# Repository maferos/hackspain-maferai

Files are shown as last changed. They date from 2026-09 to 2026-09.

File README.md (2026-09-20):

# Mafer.ai at HackSpain 2026

Our entry for the Theker track: a robot that prepares fragrance formulas from
a bench of flasks. The operator types a formula into the viewer's chat, or a
brief such as "something fresh and citrusy for summer, light" that a model turns
into one. The robot scans the bench with a fixed camera, drives its wrist camera
over each flask to read the ArUco ring that names the sample, and checks the
formula against what it found: every compound has to be on the bench, in a
flask with enough left for the dose. It then picks each flask in turn while the
panels follow the order step by step, down to the mass on the balance pan. The
lab is a UR10e on a rail, simulated in MuJoCo; the demo also replays the same
scan rendered in Isaac Sim.

Presentation video: https://youtu.be/kdZ4qXKVD1E

Isaac Lab render of a formula end to end: https://youtu.be/przYaTslfyA

Robot lab demo: https://youtu.be/lOhIzaWrY-g

Each part has its own README:

- [`simulation/`](simulation/) — robotic lab-automation simulation with MuJoCo + AutoBio. See [`simulation/README.md`](simulation/README.md).
- [`computer-vision/`](computer-vision/) — computer-vision pipeline: barcode identity, single-camera placement and the vessel detector. See [`computer-vision/README.md`](computer-vision/README.md); the detector choice and its benchmark are in [`computer-vision/docs/BENCHMARK.md`](computer-vision/docs/BENCHMARK.md).
- [`view/`](view/) — robot viewer for the live demo: Isaac Sim renders or live MuJoCo streams, plus task, robot and balance panels. See [`view/README.md`](view/README.md).
- [`dashboard/bridge/`](dashboard/bridge/) — `labbridge`, which publishes the lab state the viewer reads over WebSocket. See [`dashboard/bridge/README.md`](dashboard/bridge/README.md).

## Team

- Eki Gonzalez
- Nacho Gris
- Martí Martinez
- Eloi Torrents

## Requirements

- Python 3.10+ with [`uv`](https://docs.astral.sh/uv/); `simulation/install.sh` creates the venv the viewer backend also uses. The `mujoco` wheel ships the engine and viewer, but AutoBio needs its own MuJoCo 3.3.0 venv and only runs on Linux.
- Node for the viewer frontend (`npm install` in `view/frontend`).
- The MuJoCo Menagerie submodule for the UR10e and gripper meshes: `git submodule update --init third_party/mujoco_menagerie` from `simulation/`.
- A GPU is optional. CPU is enough for the simulation and the panels; detection and rendering are real time only with CUDA or MPS. The Isaac Sim replay videos were rendered on an NVIDIA L4 and are checked in.
- `ANTHROPIC_API_KEY` in `view/backend/.env` for the brief and formula chat; without it the chat falls back to an offline parser.

## Run locally

All from the repo root. The backend runs in `simulation/.venv`, which also
serves the MuJoCo scene.

```sh
# 1. Meshes for the UR10e and the gripper
git submodule update --init simulation/third_party/mujoco_menagerie

# 2. Python venv with the simulation and the viewer backend
(cd simulation && ./install.sh)
uv pip install --python simulation/.venv/bin/python -r view/backend/requirements.txt

# 3. Backend on :8000 (cameras, scan, lab state on :8765). The detector weights
#    are in computer-vision/weights/.
simulation/.venv/bin/python view/backend/server.py

# 4. Frontend on :5173, in another terminal
cd view/frontend && npm install && npm run dev
```

Open http://localhost:5173. Real time shows the live MuJoCo scan; the Replay
switch in the header plays the Isaac Sim recordings for the same bench layout.
Without a backend the panels play the recorded run in `view/frontend/public/scripted-run.json`.
`view/README.md` has the environment variables and the scene selection.

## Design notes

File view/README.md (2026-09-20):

# Robot viewer

Frontend to watch the mini-Hannover MuJoCo scene live: main viewport switchable
between the robot's onboard camera and the fixed scene-overview camera, a
picture-in-picture subwindow showing the other one (click it to swap), and
panels under it that follow the bench scan live, and a chat down the right-hand
side to check a formula against what the scan found.

- `backend/` — FastAPI server. The default rail scene runs the initial bench
  scan from `simulation/scripts/vision_pick.py` with the Robotiq gripper.
  The fixed `general` camera proposes bottles with YOLO; the arm moves its
  `arm_eih` camera to read their ArUco rings. Both live views stream through
  `/ws/camera/robot` and `/ws/camera/scene` (legacy MJPEG is also available).
- `frontend/` — React + Vite app. Real time shows the scan's cameras, current
  action and identified count. Boxes turn green and gain a sample ID after a
  ring is read. Replay continues to show the recorded Isaac videos.

The scan reuses the original perception and physics controller, in manual mode:
there is no automatic picking after the initial scan. It keeps watching the
bench, and saves its map to `simulation/out/view_bench_map.json`. `/api/scan`
reports startup, progress, completion and errors. Missing weights or a failed
controller are shown in the viewport; they do not fall back to a scripted sweep.
The scan runs independently of the Boxes toggle and the selected viewport mode.
Its speed depends on local physics, rendering and inference performance.

The Balance, Current formula and Formulas asked panels show this scan, in both
modes (see Lab state panels below).

## Run it

The MuJoCo model and confidence threshold are intentionally hardcoded in
`backend/detector_config.py`: `yolo26n_full_1920_e25.pt` at 0.41. Copy the file
into `computer-vision/weights/`. Upgrading the detector requires editing that
code and restarting the backend; environment variables cannot select a model
or override its threshold. Both live scanning and live box detection share
these constants. Missing weights produce an error instead of loading an older
model. Replay's separate model is pinned in the same file.

The viewer uses camera WebSockets so multiple open tabs do not exhaust the
browser's per-host HTTP connection limit. Cameras reconnect automatically
after a backend restart and show “Connecting camera…” until a frame arrives.
The main view requests 1920×1080 at up to 15 FPS; the small preview requests
640×360 at up to 5 FPS. Swapping cameras updates these subscriptions. A camera
used as a main view in another tab retains full rendering quality. The general
camera always renders at 1080p for YOLO, even when displayed as a preview,
but drops to 5 FPS when no main view subscribes. The robot preview renders
directly at 640×360. JPEG compression runs in a separate worker with at most
one waiting frame per camera; rendering never waits for compression.

Live scanning uses the original detector's full camera image and proposal
threshold (0.10 for the rail weights), including its arm mask and flask-size
filter. YOLO runs in a subprocess; ring reading runs on the perception thread.
Replay retains its existing table crop and detection settings.

The default scene (`VIEW_SCENE=minihannover_rail_scene.xml`) uses a generated
gripper copy of the rail bench. Each frontend page load requests
a random bench layout from the four shared `minihannover_open/patterns` seeds.
The next choice excludes the current pattern. To choose a specific scene, open
`http://localhost:5173/?replay=0&scene=3`: `scene=1` through `scene=4` select
`p01` through `p04`. The scene number is independent of its internal random seed. The backend replaces the rail
scene's loose and dynamic bench samples with that catalogue population in
memory, excluding the 10 ml flasks; the reported sample count includes only
the remaining flasks. It never rewrites generated scene files. All connected tabs share the
new layout, and the viewport label shows its seed and sample count. Requests
are deduplicated per page load, including React StrictMode and network retries.
The render thread stops the previous scan and detector worker, installs the new
MuJoCo model and graphics context, and starts a fresh scan. Tracks and identities
from the old layout are discarded. Replay selects the recording for that same seed; switching modes does not
request a new layout. The current Replay recordings exclude 10 ml sample flasks.
The panel demo retains its original model, samples and `RECIPE`, so
the shared scripted-run recording continues to match the panel state.

```sh
# 1. Backend deps, into the same venv simulation/ already uses:
uv pip install --python simulation/.venv/bin/python \
  -r simulation/requirements.txt -r view/backend/requirements.txt

# 2. Fetch the robot assets once, and copy the trained detector weights:
(cd simulation && bash scripts/fetch_menagerie.sh)
# computer-vision/weights/yolo26n_rail_general.pt (see that folder's README)

# 3. Backend (serves streams + scan status + tasks on :8000):
simulation/.venv/bin/python view/backend/server.py

# 4. Frontend (:5173), in another terminal:
cd view/frontend
npm install
npm run dev
```

Then open http://localhost:5173. Set `VITE_BACKEND_URL` if the backend runs
somewhere other than `http://localhost:8000`.

By default the viewport shows the live MuJoCo cameras. Select **Replay** in
the header, or open http://localhost:5173/?replay=1, to play the Isaac Lab
3.0 EA / Isaac Sim 6.1 rail videos for the current seed. The backend supplies
the selected seed; Replay waits for that selection instead of showing a
different layout. All four patterns play the double-rail XYZ gantry with Eki's
vertical hand, without the overhead extractors. The corrected marker reader
distinguishes cap and lateral labels; each scan travels left to right at
constant height. All four play at
1920×1080, 10 fps, with normal lighting and three render updates per frame.
Their compiled sample models and exported USDs were checked: no 10 ml sample
flasks remain on the scan bench. Replay keeps the current seed when switching
from Real time.

| Pattern | Seed | Flasks | Identified | Video duration | Both views rendered in |
| --- | ---: | ---: | ---: | ---: | ---: |
| p01 | 30 | 7 | 7 | 230.9 s | 658 s |
| p02 | 176 | 22 | 22 | 80.3 s | 235 s |
| p03 | 21 | 29 | 28 | 83.5 s | 254 s |
| p04 | 327 | 33 | 32 | 91.6 s | 276 s |

P01 includes the complete run requested with `Fragancia citrica con notas woody`: the scan, Claude's **Citrus Bois** formula (six compounds), the simulated pipetting sequence and the final retreat. Its [formula](frontend/public/renders/seeds/p01/formula.json) is saved beside the videos. Liquid levels change during the run; uncapping and pipetting are mimed by the controller. The wrist camera sits close to the worktop during dosing and can show only the surface; the global camera covers the full run. The other patterns contain the scan only. The side panels continue to read live lab state.

Render times were measured on an NVIDIA L4 and include Isaac startup and
MP4 encoding, excluding scan recording, USD export and transfer. All four
recordings reach the end of their scan. P03 and p04 each leave one vessel
undetected; the identities they do read are correctly associated.
`scan_complete` marks completion of the scan controller, not complete detection
of every vessel.

The worktop is one white satin mesh within the USD Table component. Click the small view to swap cameras
without restarting playback. Files live in `frontend/public/renders/seeds/p01/`
through `p04/`; `src/replayPatterns.json` maps seeds to the videos. Replay's
YOLO WebSocket receives the pattern name and decodes that same recording.

The lab
state panels read the state publisher on :8765: either this backend, or
`python -m labbridge.mock_run --fps 0 --loop` from `dashboard/bridge`, which
renders nothing and uses far less memory. Without a publisher they play the
recorded scripted run in `frontend/public/scripted-run.json`, so the panels
show the same formulation with only `npm run dev`. After changing the scripted
run, regenerate it with `python -m labbridge.record_run` from `dashboard/bridge`.

## Bottle boxes

In Real time, the scan's tracked bottles are drawn over the general camera.
The header's **Boxes** button toggles the overlay; its setting is remembered.
Unidentified tracks show a number; confirmed samples show their catalogue ID in
green. Bottles found only by the wrist camera get a projected box as well.
Perception continues with boxes hidden and while Replay is selected. The
Live inference time, image size and track count stay on the viewport label.

For explicitly selected non-scan scenes, the optional detector runs while a
viewer subscribes, every `VIEW_DETECTOR_FRAME_STRIDE` rendered frames (default 5),
using `VIEW_DETECTOR_THREADS` torch threads (default 2). It uses the table crop
and discards intermediate frames rather than queuing inference.

It needs `ultralytics` in the backend's venv and the pinned weights.
The `full` model is the YOLO26n trained on MuJoCo renders of this scene from every
angle, which the backend finds as
`computer-vision/weights/yolo26n_full_1920_e25.pt` (not in git; get it from the
team Drive, `hackathon/weights/yolo26n_full_1920_e25`, and see
`computer-vision/weights/README.md`). The boxes use that backend's own best-F1
threshold, 0.41, pinned in `backend/detector_config.py`. Without the weights the
button is greyed out and says why. Replay uses
`yolo26n_isaac_v2.pt`, trained on Isaac renders with PWD and SMP classes. On the rail scene's test frames the model finds 99 %
of the bottles on the bench at 99.6 % precision
(`computer-vision/scripts/fixedcam_bench.py`, splits `rail_*`).

## Lab state panels

The same backend also publishes the full `LabState` (see
`dashboard/bridge/README.md` for the protocol) on `ws://localhost:8765/state`.
With the scan, that state is the scan itself (`backend/scan_state.py`, a few
times a second): vision_pick's tracks and what their rings said, the arm's
joints and gripper, the controller's caption, and its log as events. Nothing is
scripted; a panel with nothing to show says it is waiting. Scenes without the
scan still replay the scripted formulation of
`dashboard/bridge/labbridge/mock_run.py` (recipe FRG-031). It needs
`websockets` in the venv (listed in `backend/requirements.txt`).

- **Current task**, in the left drawer under the asked list: what the lab is
  doing now. A task is the bench scan or a formula, and the badge says which.
  Run id (`SCAN-P04` for seed pattern p04), status and
  simulated clock; the scan's tally (flasks named by their ring out of those on
  the bench, still to look at, not samples, out of reach); then the plan around
  the current step: park, survey, each track's ring (named, not a sample, out
  of reach, or next), and the bench map. A `SCRIPTED` badge marks the recorded
  run, which plays when no backend is running.
- **Balance**, the narrow panel at the left of the dock: `balance_2` and the
  mass on its pan, nothing else; 0.000 g when nothing is being dosed.
- **Formulas asked**, the third panel in the dock: one line per formula the
  operator has put to the chat, newest last: its name, its compounds and
  grams, and what became of it (proposed and not sent, sent as `ORD-00n`, or
  rejected at the check with the reason underneath). The chat scrolls away;
  this list does not.

## The brief chat

What the operator types is a brief, such as "something fresh and citrusy for
summer, light". It joins the queue in those words and a model writes it into a
fragrance when its turn comes (`backend/brief.py`).

The model is asked only for the creative part: a name, a family, a product
strength, one sentence of description, and a list of `(compound, percent)`. It
is never asked for the formula JSON. `harness/build_formulas.build_formula`,
the same function that built the five fragrances in `harness/formulas/`,
expands a spec that size into the harness format and refuses anything wrong
with it: percentages that do not sum to 100, a compound outside the catalogue,
an ingredient over its IFRA Category 4 limit. A formula that reaches the queue
is therefore correct by construction.

The model only sees compounds the scan has named, with the grams left in the
fullest flask of each and its IFRA ceiling. `brief.py` adds the two checks the
builder cannot make, because they are facts about this bench rather than about
perfumery: that the compound is standing here at all, and that the flask holds
the dose. A brief is composed when its turn comes, not when it is sent: while
the scan is still reading the bench, the model would only see part of the
palette.

If the builder rejects the spec, its complaint goes back to the model, which
tries again, up to `brief.ATTEMPTS` times.

`ANTHROPIC_API_KEY` in the gitignored `view/backend/.env` is required: there is
no offline path for briefs. `VIEW_BRIEF_MODEL` picks the model, default
`claude-sonnet-5`. Asking what is on the bench is still answered as a question
rather than taken as a brief.

## Formula chat

The **Formula** panel, which is the whole right-hand column, checks a formula
against the flasks the scan has named by their rings, never against the
simulator's list, and shows it as the JSON the robot will receive (the `{ }`
button on the proposal, with copy):

| Type | And |
| --- | --- |
| `What's on the bench?` | the compounds the scan has identified, with their sample ids |
| `1.2 g geraniol, 0.5 g nerol` (either order, `1,2 g`, Spanish names) | the formula, each line with the flask the scan found or "not identified on the bench" |
| `40 % geraniol, 60 % nerol, total 2 g` | the same from percentages |
| `FRG-101`, `5 g of FRG-103` | one of the five formulas in `harness/formulas`, scaled (3 g by default) |
| JSON, pasted, dropped on the panel or loaded with `{ }` | the same check; any `harness/formulas` file, this viewer's own order JSON, `[{"compound", "grams"}]` lines, or `{"id": "FRG-101", "batch_g": 3}` |
| **Send to robot**, or `send` / `dale` | the formula becomes the robot's order (below) |
| **Stop**, or `stop` / `para` | the order stops |

Without `ANTHROPIC_API_KEY` a small parser (`backend/formula_chat.py`) reads
the forms above and the panel says `OFFLINE PARSER`; with the key and
`anthropic` in the venv, Claude (`VIEW_CHAT_MODEL`, default `claude-opus-5`)
reads free-form requests and proposes formulas from the identified flasks.
Once an order is running the robot narrates in the chat each step it crosses
off, with the order's clock.

## Tasks: the scan first, then the queue

The lab does one task at a time. A task is either the bench scan or a
formula, and each has its own stage bar.

    scan task:     Scan
    formula task:  Formula → Check → Fetch → Done

The scan is always the first task and has a single step. A formula has no
scan stage: the bench is read once, and a formula that runs afterwards does not
repeat it.

A formula sent while the bench is being read is queued. It appears in
**Formulas asked** as `QUEUED` with its order id, and the Current task panel
keeps showing only the scan: its run id, its single-step bar and its plan. The
chat's button says **Add to queue** while the scan runs.

A queued formula is not checked while the scan runs, because the flasks on the
bench are not known yet. When the scan finishes, the formula at the front of
the queue is matched against the whole bench, then checked, planned and handed
to the arm. The next one waits for that to finish.

`Workflow.pump()` admits one order per call and `ScanState._pump()` calls it
every tick, so a formula sent mid-scan starts by itself when the bench is
mapped. `Workflow.order` is the front of the queue, and `Workflow.waiting()`
the rest.

## The order and its workflow

A formula the queue has admitted becomes an order (`backend/workflow.py`),
`ORD-001` onwards, one running at a time:

    order:        Formula → Check → Fetch → Done
    ingredient:   locate → pick → carry → dose → verify → return

The panels follow it: the Current task panel's stage bar and one row per
ingredient with its steps as dots, crossed off as they finish, and below it the
plan with the done steps struck through; the header's status line (`ORD-001 ·
Fetch 2/3 · 01:23`); the Balance panel with the mass on the pan; and the chat's
narration.

A failure shows on the stage that failed: a rejected formula stops at Check
with the rest of the bar skipped, and a failed dose marks Fetch. Done itself
never fails.

### The plan under each ingredient

An order that passes the check is planned by `harness/formula_to_actions`, the
same planner `harness/run_formula.py` runs offline, but against the bench this
scan is looking at rather than a lookup table from another machine.
`backend/actions.py` is the bridge: it turns the scan's shelf into the entries
the planner reads, asks the compiled scene which bottles have a free joint, and
maps each of the planner's ten verbs onto the executor step that crosses it off.

Each ingredient therefore shows its ten primitives (locate, traverse,
approach, read barcode, verify id, pick, to balance, dose, weigh, return) with
the line of English a VLA would be given and, where a skill exists behind it
(`pick`, `place`), a chip naming it. The five before the pick all belong to
`locate`, because travelling to a flask, approaching it and reading its ring is
one act for this scan and they finish together. Dosing and weighing are shown
dimmed: `armlab` has no skill for either, and the plan says so rather than
inventing one.

The plan is read-only: the six steps still run the order, and the plan is that
same order spelled out the way the robot would be told. It is built once, when
the order is made. An order the planner cannot handle has no plan.

### The check, and what a flask still holds

The check accepts or refuses a formula as a whole. If the bench can only make
part of it, nothing runs: the order goes to `rejected`, no step is attempted,
the Check stage is marked failed with the reasons, the chat says which line and
why, and a toast over the viewport asks for the compound to be restocked. Two
things fail it:

- A compound no flask on the bench carries, because the scan never named one.
- A flask without enough left in it. Flasks are not full. The lookup table
  carries a capacity and no level, so `catalogue.Levels` invents one per sample,
  derived from the sample id, so every machine and every restart agrees; about
  one flask in six starts nearly empty. `resolve` picks the fullest flask of a
  compound, not the biggest, and a dose larger than what is in it fails the
  check (`only 0.4 g left in SMP-0039 (50 ml flask)`). Dosing draws the level
  down, so the next formula's check sees what the last one used. Millilitres are
  read as grams (`G_PER_ML`); the catalogue carries no densities.

`Levels.set_ml` puts a flask at a known level, for tests and for staging a demo
where the check has to fail on cue.

**For the executor.** The order is written to
`simulation/out/formula_order.json` and served at `GET /api/formula`: the
`harness/formulas` format (`material`, `cas`, `batch_g`, `concentrate_pct`,
`samples`), plus for each line the flask the scan found (`sample_id`,
`located: {x, y, track}`) or why there is none (`problem`), the balance
(`balance_2`) and the tolerance (±0.010 g). The executor reports each step, in
process with `scene.lab.workflow.report(...)` or over HTTP:

```sh
curl -X POST localhost:8000/api/workflow/report -H 'Content-Type: application/json' \
  -d '{"ingredient": "SMP-0014", "step": "dose", "status": "active", "mass": 0.84, "note": "slow pour"}'
```

`ingredient` is the sample id, the compound or the ingredient id; `status` is
active, completed, failed or skipped; `mass` is the net balance reading for that
ingredient, which also draws the Balance chart. Reporting a step finishes the
ones before it. The backend crosses off by itself what it can see: the scan
naming the flask (locate), the controller's captions and the gripper (pick,
return), and the reported mass against the target (verify). The order closes
with QC when every step is done. `backend/example_executor.py` is a working
client of all this that does not move the arm, for trying the panels:

```sh
VIEW_FORMULA_EXECUTOR=external python view/backend/server.py
python view/backend/example_executor.py --speed 2
```

`VIEW_FORMULA_EXECUTOR` picks who takes the order: `fetch` (the default until
the real executor exists) has the arm fetch each flask through the scan
controller's own pick, locate → pick → return, and says it was fetched, not
dosed; `external` leaves the order to an executor that reports.

Three columns. The **formulas drawer** down the left stacks Formulas asked over
Current formula; the camera has the middle to itself, top to bottom; the right
column carries the Balance and Info side by side, half of it each, over the
Formula chat. Both side columns take their space from the camera rather than
covering it, and Formulas, Balance and Info each open and close from their
button in the header. The readout row disappears when both of its panels are
closed, leaving the chat the whole column. The edges between views drag to
resize them, including the split between the two drawer panels and the one
under the readouts (double-click an edge to reset it), and the layout is
remembered in the browser.

To rehearse a moment of the scripted run (scenes without the scan), start the
backend part-way and slowed down:

```sh
LAB_STATE_START=100 LAB_STATE_SPEED=0.25 simulation/.venv/bin/python view/backend/server.py
```

Replay also supports **Boxes** on the general camera. With the backend running,
`/ws/replay-detections` performs one inference at a time on the video's current
time plus the previous request's measured round-trip latency (capped at one
second). A separate process decodes the future frame; the displayed video never
waits for inference. Early results wait for their video timestamp, and boxes
older than 500 ms disappear. Loops and seeking invalidate obsolete results.
The viewport label shows measured inference and round-trip times; the side
panels continue to read live lab state.

Copy the Drive `General MAFER AI/hackathon/yolo26n_isaac_v2/best.pt` weights to
`computer-vision/weights/yolo26n_isaac_v2.pt` (pinned in `backend/detector_config.py`).
Replay detection uses Isaac v2 weights on full frames at 1600 px, with an
initial confidence cutoff of 0.25 (not a calibrated best-F1 threshold for these
videos). It requires Ultralytics in the backend environment. Box coordinates
remain in the original video's pixels; playback retains its original resolution.
The backend and frontend must use the
same `view/frontend/public/renders/seeds/<pattern>/rail_global.mp4`. Videos
continue playing without detection once the seed has been selected. Restart
the backend after upgrading from the single-video replay so it can acknowledge
the selected pattern; the frontend rejects boxes from an older backend.

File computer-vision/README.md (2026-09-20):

# computer-vision

Barcode identity for the lab robot. Every sample on the bench carries a printed
EAN-13 label; the barcode holds nothing but an identifier, and everything the
robot needs to know about the sample is looked up from that identifier in a
table.

> **What the bottles carry now.** The sample bottles in `assets/*/labelled` and in
> the MuJoCo scenes no longer wear the one-sided EAN-13 label: they wear a **ring of
> eight ArUco markers** (`DICT_4X4_250`), which a camera reads from any side and
> from three times as far. Each row of `lookup_table.json` has a `marker_id` beside
> its EAN-13 code, so both resolve to the same sample. The EAN-13 half of this
> package is unchanged and still what a printed paper label would use; see
> *The bottles carry an ArUco ring* for the measurements behind the switch.

Two halves. **Identity** --- a printed EAN-13 label per sample, and a reader
for it. **Placement** --- turning a detector's bounding box into metres on the
bench, from one camera, using the bench plane in place of a depth sensor. The
first half is everything up to *Why the encoder is hand-written*; the second
is *From a box in the image to a point on the bench*.

## The idea in one line

```
sample record --sha256--> 12 digits --EAN-13--> printed label
                              |
                       lookup_table.json
                              |
        label --reader--> code --> the sample record back again
```

The barcode is a *pointer*, not a container. Nothing about the material, the
volume or the lot is recoverable from the bars alone — resolving a code always
means consulting the table. That keeps the label stable when a record's
contents change, and keeps the printed symbol to a fixed 95 modules.

## Hash to code

EAN-13 carries twelve free decimal digits plus a check digit, which is far less
than a SHA-256 digest, so the digest is **truncated**:

| Step | Value |
| --- | --- |
| Canonical payload | `SMP-0001\|Limonene\|5989-27-5\|liquid\|10\|LOT-50378` |
| `sha256(payload)` | `59443a004775eea7...` |
| `int(digest, 16) mod 10^9` | `694390669` |
| Prefix `200`, append check digit | `2006943906698` |

The `200` prefix is the GS1 range reserved for internal and in-store codes, so
these will never collide with a real retail product.

Nine digits is about 30 bits. For a hundred samples a collision is very
unlikely, but "very unlikely" is not "impossible", so `build_registry` checks
for one and re-hashes the loser with an incrementing salt until it lands
somewhere free. The salt is recorded in the table, so the mapping stays
reproducible rather than depending on insertion luck.

Because the code is derived from the record, **changing any field changes the
barcode**. Re-print a label after editing a sample.

## Generating the labels

**The label images are not in the repo.** They are deterministic build output —
one command regenerates all 200, byte-identically:

```bash
python -m labvision.registry barcodes
```

That writes one PNG per sample — `barcodes/SMP-XXXX_<code>.png` — and rewrites
`barcodes/lookup_table.json`. Takes a few seconds.

What **is** committed is `barcodes/lookup_table.json` — the lookup table itself,
200 entries keyed by barcode. That one matters: it is the mapping, it is small
and diffable, and a decoded barcode is meaningless without it.

The images are left out because they are ~7 MB of binaries that would be
rewritten wholesale by any change to the renderer. Nothing is lost: the table
pins every code, and the generator is reproducible from it.

Flags worth knowing — `python -m labvision.registry --help`:

| Flag | Effect |
| --- | --- |
| `--count N` | Generate only the first N of the catalogue (liquids first) |
| `--module-px N` | Pixels per barcode module (default 4, floor is 2) |
| `--no-images` | Rewrite only the lookup table |
| `--seed N` | Change the lot numbers, and so every barcode |

## The reader

Two decoders sit behind one `decode_image` call, and their results are merged
rather than raced.

**OpenCV** (`cv2.barcode.BarcodeDetector`) is the primary decoder. It has two
awkward habits worth knowing:

- **It will not find a barcode that fills the frame.** It searches a fixed set of
  scales relative to the image, so a tight crop is invisible to it. The setters
  that used to widen those scales — `setDetectorScales`, `setGradientThreshold` —
  are **no longer exposed** on OpenCV 4.9, so conditioning the image is the only
  lever left. `decode_image` therefore works through a ladder of white padding
  and upscaling.
- **It does not return corner coordinates.** `detectAndDecodeMulti` hands back an
  empty points vector even on a successful decode, on every build tested here.

**The localiser + scanline reader** is the fallback, and the only path that
yields a quad. It closes the thresholded image with a kernel that is long across
the bars and short along them — which melts parallel bars into one solid blob
while leaving text alone — filters the blobs by aspect ratio, rectifies each one,
and reads it against the same module tables the encoder writes with.

**Each kernel is tried both ways round**, wide-and-flat and tall-and-narrow. A
flat kernel bridges the gaps between bars that stand upright and does nothing
for bars that lie flat, so with it alone a label in "ladder" orientation — which
is how the labels sit on the powder bottles — was never found: 35 of the 100
powder labels failed when turned a quarter turn, the 35 that OpenCV's detector
also missed. Everything after the blob is found already worked at any angle.

The two are unioned because a padding rung that decodes one label in a frame
holding four would otherwise mask the three the localiser had already read.

### Measured behaviour

Over the 200 generated labels: **200/200 decode correctly**, 189 through OpenCV
and 11 only through the fallback, all with a quad, at roughly 320 ms/image. It
was 260 ms before the kernels were tried both ways round.

Turned a quarter turn, the 100 powder labels also decode **100/100**, flat and
wrapped round a cylinder at 60, 90 and 120 degrees of arc, at full size and at
3 px/module, with no code ever misread as another.

Also verified: rotation from 0 to 90 degrees, upside-down labels, Gaussian noise
at sigma 12, 3x3 blur, 0.45x downscaling, low contrast, four labels in one
frame, and tight crops that fill the frame. The one hard requirement is that the
**whole symbol including its quiet zones is inside the image** — clip a corner
and it stops decoding.

## The resolution floor

EAN-13 is 95 modules wide, and OpenCV needs roughly **two pixels per module**, so
a label must be about **190 px wide in the frame** to decode.

This is why `render_symbol` takes *pixels per module* rather than a target
width: the caller pins the module width exactly instead of inferring it from an
image size. The default of 4 px/module gives a 460 px label, comfortably clear
of the floor.

The same floor is what forces a two-stage pipeline on real frames — locate the
label at low resolution, then rectify and decode the crop from the
full-resolution frame, never from the downscaled one.

## Why the encoder is hand-written

`python-barcode` would have done the encoding. It is installed here as a test
dependency, and the reason we do not use it for the real thing is narrower than
"one less dependency":

**It cannot decode.** The package is encode-only — there is no reader, scanner
or decoder anywhere in it. So `decode_modules` and the L/G/R tables have to
exist regardless, for `reader.py` to work at all. Using the library would
replace only the encode half and leave the two halves resting on different
tables, which is exactly what the round-trip tests are there to catch.

So the tables are ours, and `python-barcode` is used as an **independent
oracle** instead: `test_ean13.py` checks our check digit and our full 95-module
pattern against it over 1000 random codes. They agree exactly. That is more
value than importing it would have given, and the tests skip cleanly on a
machine without it.

The one genuine ergonomic win is that `render_symbol` takes *pixels per module*
directly. `python-barcode` gets there too, via `module_width` in millimetres
times `dpi`, and lands within a pixel across the symbol — so this is a
convenience, not a capability the library lacks.

## From a box in the image to a point on the bench

The second half of this package. A detector says *there is a 1 L bottle in
these pixels*; the robot needs *there is a 1 L bottle at (7.21, 2.34, 0.95)*.
One camera can do that, and here is exactly what it takes.

### Why one camera is enough

A pixel is not a point, it is a ray: the object could be anywhere along it,
and that missing degree of freedom is what a second camera or a depth sensor
normally buys back. It can be bought back for free instead, because a vessel
standing on the bench has a coordinate we already know --- its base is on the
bench plane, z = 0.95. Intersect the ray with that plane and all three
coordinates fall out. With an exact box the recovery is exact; nothing is
approximated by the geometry itself.

For glassware this is not merely the cheap option, it is the better one.
Structured-light and stereo depth sensors fail on transparent and specular
surfaces, and depth for glass is an open research problem. A geometric prior
sidesteps the sensor's worst case entirely.

### What has to be known --- yes to both sets of parameters

**Intrinsics are required.** Without a focal length in pixels and a principal
point there is no map from a pixel to a direction at all. The camera here is a
**GoPro in Linear mode**, which is one number: 92 degrees across at 16:9, so
`gopro_intrinsics(1920, 1080)` gives f = 927 px and a 60.4 degree vertical
field of view.

**Linear, not Wide, and that is not a preference.** MuJoCo's cameras are, in
its own documentation, "perfect point cameras" --- a pinhole projection with
no radial term. GoPro's native Wide capture is a fisheye and no pinhole render
can produce it. The published fields of view say which mode is which without
anyone having to take a view:

| Digital lens | H | V published | V a rectilinear lens would give | |
| --- | --- | --- | --- | --- |
| Linear | 92 deg | 61 deg | 60.4 deg | matches |
| Narrow | 73 deg | 45 deg | 45.2 deg | matches |
| Wide | 118 deg | 69 deg | 86.2 deg | does not --- fisheye |

A rectilinear lens ties its two fields of view together through the frame's
aspect ratio, `V = 2 atan(tan(H/2) * 9/16)`. Linear and Narrow obey that;
Wide misses by 17 degrees. So `gopro_intrinsics(lens="wide")` raises rather
than silently modelling a fisheye as a pinhole. If the real camera does shoot
Wide, de-warp first and hand the Brown-Conrady coefficients to `Intrinsics` ---
a 2 % barrel left uncorrected is 11 px at the frame edge, which out there is
tens of centimetres of bench. On a rendered frame distortion is exactly zero.

**Extrinsics are required, and position alone is not enough.** (7, 0, 3) fixes
where the rays start; which way they point is three more numbers, and they
matter more than anything else here: at this geometry **one degree of pan
moves the answer 44 mm and one degree of tilt 87 mm** --- larger than every
other error in this document combined. Aiming at (7, 2.5, 0.95) fixes two of
the three, and roll is zero by construction, so the camera is fully specified:

| Situation | Call |
| --- | --- |
| Simulation --- exact, nothing to calibrate | `default_camera()`, i.e. `Camera.look_at(intrinsics, (7, 0, 3), (7, 2.5, 0.95))` |
| Reading the pose back out of MuJoCo | `Camera.from_mujoco(intrinsics, data.cam_xpos[i], data.cam_xmat[i])` |
| Real hardware | `Camera.from_correspondences` --- four points on the bench whose (x, y) you measured with a tape, clicked in one frame |

The last row is not optional on a real mount. A bracket is aimed to a degree
or two at best, and a degree is 44 mm, so a physical camera has to be solved
from markers no matter how precisely its nominal aim is specified.

**Unless you take the shortcut, in which case neither is needed.** If every
answer is going to land on the same plane, the whole pinhole model collapses
into one 3x3 homography between pixels and bench coordinates, and it can be
fitted from four known points without a focal length or a pose ever being
named:

```python
homography = homography_from_points(bench_xy, image_uv)   # four points, no calibration
positions = apply_homography(np.linalg.inv(homography), boxes_bottom_centre)
```

`test_camera.py` checks this returns the same matrix the full calibration
builds. The one thing it cannot absorb is lens distortion, which is not a
projective map --- undistort first. Take this route if the camera is fixed and
nothing else needs the camera model; take the full model if you also want
vessel heights, mouths, or a second plane later.

### The room, and what the camera sees of it

14 x 5 x 3 m, origin at a floor corner, X along the long wall. Camera at
(7, 0, 3) --- ceiling height, halfway along the long wall --- aimed at
(7, 2.5, 0.95), the middle of the bench top. That is a 3.23 m line of sight at
**39 degrees of elevation**, which is a decent mounting: below about 30 degrees
the ray meets the plane at a grazing angle and pixel error slides a long way
along it.

For the simulation side, that camera is this, and MuJoCo will render exactly
the projection this package assumes:

```xml
<camera name="bench" pos="7 0 3" mode="targetbody" target="bench"
        fovy="60.4" resolution="1920 1080"/>
```

`fovy` is the vertical field of view, which is the one MuJoCo wants; 60.4
degrees is the Linear lens at 16:9. If you would rather state the optics
physically, `sensorsize="0.00605 0.0034" focal="0.00292 0.00292"` is the same
camera --- the HERO11's measured 2.92 mm lens behind the sensor rectangle that
gives the Linear field of view --- and MuJoCo computes `fovy` from it,
overriding the attribute. Pointing it with `mode="targetbody"` beats writing
a quaternion, and `Camera.from_mujoco` reads whatever pose comes out.

That camera is now mounted in `simulation/models/minihannover_scene.xml` as
`general`, with a second GoPro, `wrist`, beside it. The MuJoCo room puts its
origin under the bench, not at a floor corner: the corner this package
measures from is world (-8.5, -2.9, 0) there, so room (7, 0, 3) is world
(-1.5, -2.9, 3) --- on the right wall at ceiling height --- and
`test_scene.py` pins pose, field of view and resolution to `default_camera()`
under that shift. `wrist` stands in for the camera that will ride on the arm:
it hovers 0.30 m in front of the label of a 250 ml powder bottle on the bench,
about as close as a GoPro's fixed focus stays sharp, on a mocap body so it can
be flown around. Its 1080p frame decodes that bottle's barcode as rendered;
`general`'s frame, 2.5 m and more from every label, decodes none, which is the
division of labour: the fixed camera proposes, the wrist camera confirms.

Two numbers do **not** carry over yet. The simulated bench is centred on room
(8.5, 2.9), not (7, 2.5), and its top is at z = 0.90, not 0.95. So `general`
frames the bench off-centre --- about the last metre towards the glass
partition is out of shot --- and intersecting rays with z = 0.95 would misplace a bottle by
6 cm at this elevation. `TABLE_CENTRE` and `TABLE_TOP_Z` have to be settled
against the simulation before `locate` is run on its frames.

### What the wrist camera reads

`scripts/wrist_scan.py` flies `wrist` in front of one bottle after another,
decodes the **whole 1080p frame** --- nothing tells the reader where the label
is or which sample to expect --- and writes every frame, a contact sheet of
frame, 1:1 crop and result, and `results.json` to `simulation/out/wrist_scan/`.
It starts 0.30 m from the label, a GoPro's near focus, and steps closer until
the bottle's own code reads. The default run is the thirteen hand-placed
bottles plus seven drawn from the gantry, so every size and the scattered
library are both covered: **19 of 20 read, none misread**, and half the frames
also read a neighbour that happened to be in shot.

| Bottle | Reads from |
| --- | --- |
| Powder 2 L, 500 ml, 250 ml | 0.30 m |
| Powder 1 L | 0.30 m once, 0.20 m three times |
| Powder 100 ml | 0.20 m |
| Liquid 100 ml | 0.30 m once, 0.20 m twice |
| Liquid 50 and 20 ml | 0.15 m |
| Liquid 30 ml | 0.15 m on the bench; 0.10 m from 8 degrees above on a shelf |
| Liquid 10 ml | 0.10 m on the bench; **not at all** at the back of a shelf |

Three things this measured that the flat tests could not:

- **The small flasks need the arm closer than a GoPro focuses.** Their labels
  are small because their walls are, so 2 px per module means 0.10 to 0.15 m.
  The render has no defocus; a real GoPro at that range does. Either the wrist
  camera gets a close-focus lens, or the 10 to 30 ml labels get a denser
  symbology.
- **A shelf lip hides a label's first digits.** From level, the 20 mm lip covers
  the bottom of the label on a small flask standing well back, and for a
  ladder label the bottom is where the code starts. Looking from 8 degrees
  above clears it.
- **Do not look from far above.** The bars of a ladder label are rings round
  the bottle, and from above a ring is an arc. At 25 degrees and 0.10 m they
  bend too far for the localiser to rectify; at 8 degrees they still read. So
  the script raises the camera gently, gentlest angle first.

### ArUco against EAN-13: far reach, but not on a turned bottle

EAN-13 spends 113 modules along one axis to carry far more than the 200 ids
needed, so on a 10 ml flask a module is 0.21 mm. `scripts/aruco_experiment.py`
puts a `DICT_4X4_250` ArUco marker, 8 modules a side with its quiet zone, where
the EAN-13 label is --- as large a square as the wall height and 90 degrees of
arc allow --- and measures both through the same 1080p GoPro pinhole in MuJoCo.
Nothing committed is touched; output goes to `simulation/out/aruco_experiment/`.

| Vessel | EAN module | ArUco module | EAN reads to | ArUco reads to | EAN max turn | ArUco max turn |
| --- | --- | --- | --- | --- | --- | --- |
| flask_10ml | 0.21 mm | 2.20 mm | 0.15 m | 1.0 m | 80 deg | 20 deg |
| flask_20ml | 0.30 mm | 2.76 mm | 0.2 m | 1.0 m | 80 deg | 10 deg |
| flask_30ml | 0.36 mm | 3.16 mm | 0.2 m | 1.5 m | 80 deg | 10 deg |
| flask_50ml | 0.43 mm | 3.73 mm | 0.3 m | 1.5 m | 80 deg | 10 deg |
| flask_100ml | 0.58 mm | 4.70 mm | 0.5 m | 2.0 m | 80 deg | 10 deg |
| bottle_100ml | 0.32 mm | 4.56 mm | 0.2 m | 2.0 m | 70 deg | 20 deg |
| bottle_250ml | 0.48 mm | 5.93 mm | 0.2 m | 2.5 m | 70 deg | 10 deg |
| bottle_500ml | 0.65 mm | 7.30 mm | 0.5 m | 3.0 m | 50 deg | 10 deg |
| bottle_1000ml | 0.66 mm | 8.68 mm | 0.5 m | 4.0 m | 40 deg | 20 deg |
| bottle_2000ml | 0.66 mm | 9.98 mm | 0.5 m | 4.0 m | 50 deg | 20 deg |

Reach is square on, in a plainly lit scene with nothing else in shot, so the
EAN-13 column is a little kinder than `wrist_scan.py` found in the room. Turn is
the bottle turned about its own axis, measured at half the reach so that it is
angle and not resolution that fails. No id was ever read as another.

- **ArUco reads from 4 to 12 times farther**, because its modules are about ten
  times larger. The smallest flask reads from 1 m, past a GoPro's 0.30 m near
  focus, and the large powder bottles from the fixed camera's range.
- **Rolling the camera does not matter** to either code: all seven rolls read.
- **Turning the bottle is what ArUco cannot take**: it is lost 10 to 20 degrees
  off square, where the ladder EAN-13 holds to 40 to 80. A turned cylinder
  squeezes the near and far halves of a square marker by different amounts,
  which is not a perspective distortion, so the detector samples the bits in
  the wrong places. The EAN-13's bars are rings, and a turn only shortens them.
- Narrower markers trade reach for turn (`--arc`): 30 degrees of arc holds to
  30 to 40 degrees of turn, and reads 10 ml / 100 ml / 2 L from 0.3 / 0.75 /
  1.5 m, still about twice the EAN-13.

So a single ArUco on the wall is not a replacement. What would work is a ring
of about eight narrow markers, one every 45 degrees, read from any side at two
to three times the EAN-13's reach; or the marker on the flat cap top, where
there is no curvature and the bottle's turn is irrelevant, at the price that a
cap can end up on the wrong bottle. Neither is built yet.

### Labels that go all the way round

A bottle put down by hand faces wherever it faces, and a label on one side is
invisible from the other. `scripts/ring_experiment.py` measures two labels that
have no side against the two that do, on every bottle size, turning the bottle
through a full turn in 15 degree steps, and draws `comparison.png`:

- **EAN-13 ring.** The ladder EAN-13's bars already run round the bottle;
  stretched to 360 degrees every bar is a full ring. Same symbol, same module.
  It is read without a localiser --- the code is the bottle --- by laying down a
  vertical strip from the middle of the bottle's box for `decode_scanline`.
- **ArUco ring.** Eight copies of one `DICT_4X4_250` marker, one every 45
  degrees, since a single marker is lost 10 to 20 degrees off square.

| Vessel | Reach: EAN / EAN ring / ArUco / ArUco ring | Turns read from 0.30 m, of 24: same order |
| --- | --- | --- |
| flask_10ml | 0.15 / 0.15 / 1.0 / 0.4 m | 0 / 0 / 3 / **24** |
| flask_20ml | 0.2 / 0.2 / 1.5 / 0.75 m | 0 / 0 / 3 / **24** |
| flask_30ml | 0.3 / 0.3 / 1.5 / 0.5 m | 6 / **24** / 3 / **24** |
| flask_50ml | 0.3 / 0.3 / 2.0 / 0.75 m | 7 / **24** / 3 / **24** |
| flask_100ml | 0.5 / 0.5 / 2.5 / 0.75 m | 10 / **24** / 3 / **24** |
| bottle_100ml | 0.2 / 0.2 / 2.5 / 1.0 m | 0 / 0 / 3 / **24** |
| bottle_250ml | 0.4 / 0.4 / 2.5 / 1.0 m | 8 / **24** / 3 / **24** |
| bottle_500ml | 0.5 / 0.5 / 5.0 / 2.0 m | 7 / **24** / 3 / **24** |
| bottle_1000ml | 0.5 / 0.5 / 5.0 / 1.5 m | 8 / **24** / 3 / **24** |
| bottle_2000ml | 0.5 / 0.5 / 4.0 / 2.5 m | 8 / **24** / 3 / **24** |

Frames are cropped to the bottle, as a detector's box would, and the scene is
plainly lit with nothing else in shot. At half of each label's own reach both
rings read 24 of 24 turns on every bottle; the one-sided EAN-13 reads 7 to 10
and the one-sided ArUco 1 to 4. No id was read as another.

- **Both rings make the bottle's turn irrelevant.** Today's label is readable
  from about a third of the directions a bottle can face.
- **The EAN-13 ring costs nothing in reach and gains nothing**: same module, so
  the 10 and 20 ml flasks and the 100 ml powder bottle still cannot be read
  from a GoPro's 0.30 m near focus. It keeps the hash-derived code, the lookup
  table and handheld scanners, and drops the printed text beside the bars.
- **The ArUco ring is the only label that reads every bottle, however it is
  turned, from 0.30 m**, and it reads from 0.4 to 2.5 m: two to five times the
  EAN-13. It pays for going round with half the single marker's module.
- The two are not exclusive where the wall is tall enough: an ArUco ring for
  the robot above an EAN-13 ring for people and scanners.

### The bottles carry an ArUco ring

`labvision.bottles` now builds every kit with `label="aruco_ring"`: one marker
of `DICT_4X4_250`, eight times round the straight wall, one copy every 45
degrees, as tall as an eighth of the circumference. The marker is the sample's
`marker_id`, its position in the catalogue (0 to 199) --- dealt out rather than
hashed, because a dictionary of 250 ids would collide --- and the lookup table
carries it on every row (schema version 5 added it; version 6 dropped powder). `label="ean13"` still builds the
one-sided barcode label, and `python -m labvision.bottles --label ean13`
regenerates the old kits.

| Bottle | EAN-13 module | Ring module |
| --- | --- | --- |
| Liquid 10 / 20 / 30 / 50 / 100 ml | 0.21 / 0.30 / 0.36 / 0.43 / 0.58 mm | 1.10 / 1.38 / 1.58 / 1.87 / 2.35 mm |
| Powder 100 / 250 / 500 ml / 1 / 2 L | 0.32 / 0.48 / 0.65 / 0.66 / 0.66 mm | 2.28 / 2.96 / 3.65 / 4.34 / 5.71 mm |

Measured in the minihannover scene, before and after, with `wrist_scan.py` on the
same 40 bottles (the 13 placed by hand and 27 drawn from the gantry), decoding
the whole 1080p frame. `--approach aisle` comes at each bottle from the aisle it
stands beside, not knowing which way it is turned, which is what an arm gets;
`--approach label` parks square to the label, the barcode's best case.
`scripts/wrist_compare.py` draws the figure.

| | Read | Read from 0.30 m | Had to come closer | Not read | Misread |
| --- | --- | --- | --- | --- | --- |
| EAN-13, square to the label | 38 / 40 | 10 | 28 | 2 | 0 |
| EAN-13, from the aisle | 37 / 40 | 12 | 25 | 3 | 0 |
| **ArUco ring, from the aisle** | **40 / 40** | **38** | 2 | 0 | 0 |

0.30 m is a GoPro's near focus, so it is the distance that counts: the ring
reads 38 of 40 bottles from there against 12, every flask size included, and the
two it has to approach (to 0.10 m) are hidden behind a neighbour from the aisle.
The EAN-13's misses are 10 and 20 ml flasks at the back of a shelf. A frame
with a ring in it also reads the neighbours: 107 other bottles were identified
in passing, against 38, which is a fixed camera's job done by the wrist.

What the ring gives up: a handheld retail scanner cannot read it, and the label
no longer prints the material's name. Both can come back as a text strip or an
EAN-13 beside the ring on the bottles whose wall is tall enough.

What the frame actually contains, with a 92 x 60.4 degree lens aimed there:

| Image row | What is there |
| --- | --- |
| 0 to 255 | the far wall and above --- **not bench** |
| 255 | the foot of the far wall, bench y = 5.0 |
| 540 | the bench centre, y = 2.5 |
| 1080 | the nearest visible bench, y = 0.76 |

So three quarters of the frame height is usable bench, and the near 0.76 m
strip against the camera's own wall is out of shot. The horizon sits at
v = -221, above the frame entirely, which means no pixel in a valid frame can
fail the horizon test --- if a box trips that guard, the box is malformed.

One number in `scene.py` is still unknown: **the bench footprint**, so
`TABLE_SIZE` is None and the "is it even on the table" check is skipped.

### Which pixel of the box

A box is four numbers and a position is two, so something has to say what
stands for the object. Three ways, in decreasing order of what they need and
increasing order of error:

**`fit`** --- invert the forward model. `predict_bbox` computes the exact box
an upright cylinder of known radius and height would produce, so the position
is just the one whose predicted box matches the observed one: Gauss-Newton on
the four edge residuals, started from the base anchor, converging in two or
three steps and 0.7 ms. It uses all four edges instead of throwing three away,
and it has **no anchor bias at all**. It also returns a residual, which is the
only thing in the pipeline that notices a detection labelled as the wrong
vessel. This is the default whenever the dimensions are known --- and for powders
they are, since `scene.VESSELS` is keyed by `Sample.vessel_class`, so a
decoded barcode indexes straight into it. The liquid `flask_*` classes have
no dimensions recorded anywhere yet, so they fall back to the base anchor
until someone measures them.

**`base`** --- back-project the **bottom-centre** of the box, which images the
contact patch and so is already on the plane. Needs no height. It has one bias
that must be corrected: the lowest pixel of a vessel of radius r is not its
axis but the point of its base circle nearest the camera, so the raw
intersection lands short by exactly r. The direction to push it back is not
"towards the camera along the floor" --- it is the in-plane normal to the
iso-v line, which falls straight out of the Jacobian. Skip that correction and
these bottles land **23 to 59 mm** off, which dwarfs the pixel noise.

**`centre`** --- back-project the **centre** of the box against a plane lifted
to half the vessel height. For when the base is occluded or cropped. Needs the
height, and keeps a residual bias because the box centre is not the image of
the mid-height point under perspective.

Whichever is used, the answer returned is the base centre on the bench; the
mouth, which is where a pipette goes, is that plus the vessel height.

### Measured

Against exact boxes --- `predict_bbox` is the oracle, so ground truth is known
--- over 25 positions spanning a 1.6 m square of bench, mean error in mm:

| Vessel | `fit` | `centre` | `base` | `base`, correction off |
| --- | --- | --- | --- | --- |
| bottle_100ml | 0.00 | 0.7 | 3.2 | 23 |
| bottle_250ml | 0.00 | 1.2 | 4.4 | 30 |
| bottle_500ml | 0.00 | 1.9 | 5.6 | 38 |
| bottle_1000ml | 0.00 | 3.2 | 7.9 | 45 |
| bottle_1000ml_wide | 0.00 | 2.3 | 5.6 | 51 |
| bottle_2000ml | 0.00 | 4.1 | 8.5 | 59 |

The residual on `base` is entirely the box's u-centre drifting off the axis for
off-axis vessels --- feed it the true lowest silhouette pixel instead and the
error is 0.00 mm, which is what says the radius correction itself is right
rather than merely helpful.

There is deliberately no resolution column. These biases are **geometry**: they
come from where the silhouette's extremes sit in the world, and a focal length
only rescales that. Halve the frame and every number in the table is unchanged,
which `test_the_anchor_bias_is_geometry_and_does_not_move_with_resolution`
pins.

### The real limit is resolution, not geometry

Since the geometry contributes nothing, all the error is the detector's,
amplified by how many millimetres of bench a pixel covers. `plane_jacobian`
gives that exactly, and its worst singular value is what `Placement` reports:

| GoPro Linear at | Near edge | Bench centre | Far edge |
| --- | --- | --- | --- |
| 1920 x 1080 | 3.2 mm/px | 5.5 mm/px | 8.4 mm/px |
| 3840 x 2160 (4K) | 1.6 mm/px | 2.7 mm/px | 4.2 mm/px |
| 5312 x 2988 (5.3K) | 1.2 mm/px | 2.0 mm/px | 3.1 mm/px |

Which lands as, for a 1 L bottle at 1080p with the `fit` anchor --- where its
box is about 26 x 72 px:

| Box noise | Mean error | p95 |
| --- | --- | --- |
| 0.5 px | 2 mm | 5 mm |
| 1 px | 4 mm | 9 mm |
| 2 px | 8 mm | 17 mm |
| 3 px | 12 mm | 26 mm |
| 5 px | 21 mm | 50 mm |

So at 1080p from 3.2 m **a pixel is worth 5.5 mm of bench**, and a detector
good to a pixel or two lands within a centimetre --- enough to reach into a
50 mm bottle mouth, not enough to be careless about. The levers, in order of
effect: shoot 4K or 5.3K, which the camera does natively and which buys 2x and
2.8x; switch the digital lens from Linear to Narrow, which trades a third of
the field of view for a quarter off the error; move the camera closer; raise
the mounting angle. None of them is a change to the maths.

The wide end is where this gets dangerous. Every step towards a wider lens
spends pixels on wall: Wide would be worse still, and it cannot be rendered or
back-projected as a pinhole anyway. An action camera is the wrong instrument
for a measurement like this, and Linear at 4K is about the best one can be
asked to do.

### Where this stops being true

The plane has to be real. A vessel in a rack, on a shelf, held by the gripper
or knocked over is not at z = 0.95, and the error is systematic rather than
noisy --- 5 cm of unmodelled height at this geometry is about 6 cm of position
error. If vessels can sit at several known heights, classify the surface and
switch planes. If the heights are arbitrary, one camera is not enough and this
approach does not apply.

Three guards are reported rather than assumed away: `clipped` (the box touches
the frame border, so its edges are the frame's and not the object's),
`inside_room` / `on_table`, and the `fit` residual. A detection above the
horizon raises instead --- geometrically, it cannot be standing on the bench.

### Using it

```bash
# Where is this box, and how much is a pixel worth there?
python -m labvision.scene --bbox 300 200 340 280 --vessel bottle_1000ml

# The room's error budget, no detection needed
python -m labvision.scene

# At 4K, or with a narrower digital lens
python -m labvision.scene --width 3840 --height 2160 --lens narrow
```

```python
from labvision import scene
from labvision.camera import Camera

# In simulation the camera is fully specified, so this is exact
camera = scene.default_camera()

# On real hardware, solve the pose from four measured markers on the bench
intrinsics = scene.gopro_intrinsics(1920, 1080)          # or 3840, 2160
camera = Camera.from_correspondences(intrinsics, marker_pixels, marker_world_xyz)

# Per detection
placed = scene.locate(scene.BBox(*box), camera, vessel=scene.VESSELS["bottle_1000ml"])
placed.position          # base centre, metres, on the bench plane
placed.mouth             # where the pipette goes
placed.metres_per_pixel  # what a pixel of detection error costs here
placed.residual_px       # how well the box matches that vessel standing there
```

## Layout

| Path | Purpose |
| --- | --- |
| `labvision/ean13.py` | Check digit, module encode/decode, rendering |
| `labvision/registry.py` | Samples, hash-to-code, lookup table, label PNGs |
| `labvision/reader.py` | Localiser, both decoders, code-to-sample resolution |
| `labvision/camera.py` | Pinhole model, ray-plane intersection, homography |
| `labvision/scene.py` | The room, box anchors, box-to-position |
| `labvision/bottles.py` | Sticks each label onto the bottle of its phase and size |
| `labvision/detector.py` | YOLO backends (YOLO-World, YOLO26 COCO, the fine-tuned fixed-camera YOLO26n): a frame in, bottle boxes out |
| `labvision/evaluation.py` | Scores detector boxes against simulator truth; the worktop filter for the fixed camera |
| `labvision/identify.py` | Reads the ArUco ring inside a detector box, or the whole frame, and names the sample |
| `labvision/perception.py` | The fixed camera proposes, the wrist camera confirms and places the bottle |
| `labvision/world.py` | The bottles the vision system found, in the console's vessel shape |
| `tests/` | 386 tests, plus 33 doctests |
| `barcodes/lookup_table.json` | The committed lookup table, 200 entries |

## Usage

```bash
# requirements.txt adds PyPI as an extra index, so this works without touching
# your global pip.conf and without a valid CodeArtifact token
pip install -r requirements.txt

# Generate all 200 labels and the lookup table (labels are gitignored)
python -m labvision.registry barcodes

# Read a label back and resolve it
python -m labvision.reader barcodes/SMP-0001_2006943906698.png \
                        barcodes/PWD-0001_2005217175150.png

# Anything OpenCV can open, several files at once, as JSON
python -m labvision.reader photo.jpg --table barcodes/lookup_table.json --json

# Where on the bench is this detection?
python -m labvision.scene --bbox 300 200 340 280 --vessel bottle_1000ml

pytest tests
pytest --doctest-modules labvision
```

`python -m labvision.registry --help` covers `--count`, `--seed`, `--module-px`
and `--no-images`.

### From Python

```python
from pathlib import Path

import cv2

from labvision import reader, registry

table = registry.load_table(Path("barcodes/lookup_table.json"))
for detection, record in reader.resolve(
    reader.decode_image(cv2.imread("frame.png")), table
):
    print(detection.code, record["material"], detection.corners)
```

## Sample catalogue

**200 barcodes: 40 liquid compounds, each in five flask sizes — a full cross
product of compound x container.** As of registry **version 6** the catalogue is
liquids only, so every one of the 250 `DICT_4X4_250` markers is free for a sample
and the bench carries 200 distinct labels with nothing repeated.

| Phase | Compounds | Containers | Ids | Codes |
| --- | --- | --- | --- | --- |
| Liquid | 40 | flasks — 10, 20, 30, 50, 100 ml | `SMP-0001..0200` | 200 |

Material varies slowest, so `SMP-0001..0005` are the first compound (Limonene) at
each flask size. Only the lot number is random, under `DEFAULT_SEED`.
`SMP-0001..0100` keep the codes and markers they had in version 5; the 20 added
compounds are `SMP-0101..0200`.

**The liquids live in flasks**, so there are five vessel classes: `flask_10ml`,
`flask_20ml`, `flask_30ml`, `flask_50ml`, `flask_100ml`.

### Powder left the catalogue at version 6 (but not the code)

Versions 4–5 catalogued 100 powders (`PWD-*`) in white HDPE bottles beside the
liquids, which spent half the marker dictionary. Version 6 drops the powder phase
so all 250 ids go to liquids. What **stays**: `POWDER_MATERIALS` and the `POWDER`
phase spec in `registry.py`, the agrochemical bottle kit in
`assets/agrochemical-bottles` (five sizes: `Bote_100mL` Ø46 / `_250mL` Ø60 /
`_500mL` Ø74 / `_1L` Ø88 / `_2L` Ø116 mm), and the powder path in `bottles.py` —
so a hand-made powder sample still resolves its labware and labels correctly, and
a future catalogue can bring powders back by adding `POWDER` to `PHASES`.
`scene.VESSELS` still carries those bottle dimensions.

> **The measured tables further down that name `bottle_*` sizes** (decode reach,
> ArUco vs EAN-13, placement error, detector size floor) were taken on the
> earlier liquid+powder catalogue and its bottles. They are kept as the record of
> what was measured; the geometry they describe is still what `scene.VESSELS`
> holds, but the catalogue no longer generates powder samples.

### Phase is a property of the compound, not a choice

A compound is solid or liquid at room temperature; it does not get to be both.
`POWDER_MATERIALS` (kept for the reasons above) carries each solid's melting point
as a comment, which is the evidence for it being there:

| Compound | mp °C | | Compound | mp °C |
| --- | --- | --- | --- | --- |
| Camphor | 175–177 | | Vanillin | 81–83 |
| Maltol | 160–164 | | Phenylacetic acid | 76–78 |
| Musk ketone | 135–137 | | Ethylvanillin | 76–78 |
| Cinnamic acid | 133 | | Coumarin | 69–71 |
| Sclareolide | 120–124 | | Tonalide | 54 |
| Ethyl maltol | 89–92 | | Indole | 52–54 |
| Thymol | 49–51 | | Cedryl acetate | 44–46 |
| Benzyl cinnamate | 39 | | Menthol | 36–38 |
| Piperonal | 35–37 | | Exaltolide | 35 |
| Methyl cinnamate | 34–38 | | Diphenyl ether | 27–29 |

Four of these — **Camphor, Vanillin, Thymol and Menthol** — were originally in
the liquid list. They are not liquids, and moving them is why the liquid codes
were reissued when powders were added. Their replacements are Phenylethyl
alcohol, Methyl salicylate, Linalyl acetate and cis-3-Hexen-1-ol.

Two borderline cases stay in the liquid list deliberately: **Anethole**
(mp 20–21 °C) and **alpha-Terpineol** (mp ~35 °C) are both solid on a cold
bench, but are supplied and handled as liquids commercially.

`test_no_compound_appears_in_both_phases` and
`test_cas_numbers_are_unique_across_the_catalogue` keep this honest.

### Why a cross product and not two cycling lists

The earlier version cycled 20 materials against 5 vessel classes in step. Since
5 divides 20, that locked each compound to exactly one vessel size — Limonene
was always the 50 ml tube — covering just 20 of the 100 possible pairs.

That is fine for exercising the barcode path and wrong for training data: a
vision model could learn *flask size implies compound* and never read the
barcode at all. `test_compound_is_not_correlated_with_container_size` guards it.

### A note on the flask sizes

10, 20, 50 and 100 ml are standard volumetric-flask capacities (ISO 1042). 30 ml
is **not** in that series — its neighbour there is 25 ml — but it is a common
amber storage-bottle size for aroma chemicals, which is the closer analogue for
a raw-material inventory. Change one entry in `FLASK_VOLUMES_ML` and regenerate
if you want strict ISO sizes.

## Labels on the bottles

```bash
python -m labvision.bottles                 # every catalogued phase (liquids only, v6)
python -m labvision.bottles --phase liquid  # just one phase
```

Each phase has a kit of bottle models under `assets/`, and every sample gets a
copy of its bottle with its label stuck on:

| Phase | Kit | Bottles | Labelled models |
| --- | --- | --- | --- |
| Liquid | `assets/amber-bottles` | amber glass, closed, white cap | `labelled/SMP-XXXX_<code>.glb`, 200 files, ~62 MB |

The powder kit (`assets/agrochemical-bottles`, white HDPE) is no longer
catalogued (registry v6); its `labelled/PWD-XXXX_<code>.glb` files remain from
version 5 for whenever powders return, but `python -m labvision.bottles` builds
only the catalogued liquids now.

The liquid sizes — 10, 20, 30, 50, 100 ml — are exactly the amber kit's, so no
liquid barcode had to change. The kit also has a 60 ml bottle that no sample
uses: adding a size renumbers the samples, which reissues every liquid barcode.
In the registry the liquid `vessel_class` is still `flask_*ml`; the name predates
the kit and renaming it is a schema change for another day.

Unlike the label PNGs these models **are committed**, so the simulation side can
use them without installing this package. They are deterministic: regenerating
from the same lookup table rewrites them byte for byte, so rerun the command and
commit the result whenever a barcode, the label layout or a kit's bottles
change. A file whose name no longer matches a row of the table is stale and
should be deleted. `test_committed_labelled_bottles_are_not_stale` fails when
they drift.

**The bottle is never chosen, it is looked up.** `labelled_bottle` takes a
registry row and nothing else; the kit comes from that row's `phase` and the
bottle from its `container_ml`, so a 2 L barcode cannot land on a 100 ml bottle,
nor a liquid's on a powder bottle — 100 ml exists in both kits, and the phase
decides which one it is.

The kit's GLBs have no UVs, so the label is not painted on. It is a separate
**sticker mesh**: a thin curved patch 0.2 mm off the bottle's straight wall, with
its own UVs and the label PNG embedded as its texture, added as a child node of
the bottle. The bottle's meshes and materials are carried over byte for byte. The
wall is measured from the GLB, not copied from the kit's generator, so a
regenerated kit needs no change here. The amber files hold a closed bottle, with
the cap listed first, so the bottle is taken to be the tallest mesh in the file.

**On glass the sticker has a back.** The amber bottles are see-through, which a
one-sided sticker handles badly either way: drawn on one side it vanishes when
seen from behind through the bottle, and drawn on both it shows its barcode
mirrored through the glass — which the reader will happily decode, since it
reads mirrored symbols. So on a bottle whose material transmits light the label
gets a second, plain white face turned inwards, as the back of a paper label is.
The opaque HDPE bottles do not need one and do not get one.

The label node carries `extras` a consumer can read without decoding anything:
`code`, `sample_id`, `material`, `container_ml`, `vessel_class`, `module_mm` and
`corners_m` — the label's four corners in the bottle's frame, top-left first,
which are the ground-truth keypoints for the label quad.

### Turned a quarter turn, and why

The label goes on in **ladder orientation**: bars lying flat, stacked up the
bottle, text reading bottom to top. The embedded texture stays an upright label,
identical to the PNG `labvision.registry` writes; it is the sticker's UVs that
turn it. `corners_m` is named in the label's own frame for the same reason, so
its top-left is the sticker's bottom-left as seen on the bottle.

This is about what a cylinder does to a barcode. Seen head-on, a cylinder
squeezes whatever runs *round* it, more towards the edges, and leaves alone
whatever runs *up* it. A barcode's information is entirely in its bar widths.
Upright, those widths run round the bottle and get squeezed unevenly, and the
reader, which expects even modules, gives up. Turned, only the bar *lengths* are
squeezed, and they carry nothing.

All 100 powder labels, projected onto a cylinder and decoded:

| Arc covered | 45° | 55° | 60° | 75° | 90° | 120° |
| --- | --- | --- | --- | --- | --- | --- |
| Upright | 100 | 100 | 86 | 72 | 74 | — |
| Ladder | — | — | 100 | — | 100 | 100 |

Upright there is a cliff just under 60 degrees, and staying below it meant a
20 mm label at 51 % magnification on the 100 ml bottle. Ladder has no such
limit, so the labels are sized by the wall instead.

### Label size follows the bottle

Each label is printed as large as three limits allow: 200 % magnification, which
is the EAN-13 specification's own ceiling; the height of the straight wall less a
3 mm margin; and 90 degrees of circumference, which is there to keep the captions
in view and never binds on this kit.

| Bottle | Sticker (round x up) | Module | Magnification | Arc | Bound by |
| --- | --- | --- | --- | --- | --- |
| Liquid 10 ml | 12.3 x 25.3 mm | 0.21 mm | 63 % | 63° | wall height |
| Liquid 20 ml | 17.9 x 36.8 mm | 0.30 mm | 92 % | 73° | wall height |
| Liquid 30 ml | 21.2 x 43.5 mm | 0.36 mm | 109 % | 76° | wall height |
| Liquid 50 ml | 25.4 x 52.0 mm | 0.43 mm | 130 % | 76° | wall height |
| Liquid 100 ml | 34.0 x 69.7 mm | 0.58 mm | 174 % | 81° | wall height |
| Powder 100 ml | 18.7 x 38.3 mm | 0.32 mm | 96 % | 46° | wall height |
| Powder 250 ml | 28.5 x 58.5 mm | 0.48 mm | 147 % | 54° | wall height |
| Powder 500 ml | 38.4 x 78.7 mm | 0.65 mm | 197 % | 59° | wall height |
| Powder 1 L | 38.9 x 79.9 mm | 0.66 mm | 200 % | 50° | magnification |
| Powder 2 L | 38.9 x 79.9 mm | 0.66 mm | 200 % | 38° | magnification |

Every liquid label fills its wall top to bottom, so it cannot be made larger
without changing the label itself: the amber bottles are simply short. The 10 ml
one is 52 mm tall with 31 mm of straight wall, and its label comes out at 63 %.
Stood upright instead, and kept under the 55 degrees an upright label survives,
the same label would be 11 mm wide at 27 %. The amber labels also wrap further
round their narrow bottles than the powder ones, up to 81 degrees, which is well
inside what ladder orientation was measured to take.

At the reader's floor of two pixels per module the 10 ml liquid label needs about
10 px/mm in the frame, the 100 ml powder label about 6, and the 1 L and 2 L
about 3.
`test_embedded_label_decodes_flat_and_wrapped` pins the decode for every size as
a camera would see it, and
`test_ladder_labels_survive_far_more_wrap_than_upright_ones` pins the table above.

**What this does not show.** The wrap test is a head-on orthographic projection
of a clean texture. A rendered frame adds perspective, a bottle turned partly
away, lighting and the camera's resolution, none of which are tested here yet.

## Not done yet

The labelled bottles are in the MuJoCo scene: `simulation/tools/build_labelled_bottles.py`
turns the GLBs into MJCF bodies with the sticker as an OBJ plus a PNG texture, and
`simulation/models/minihannover_scene.xml` uses them for every sample container:
all thirteen hand-placed samples are liquids now. The first decode from a rendered frame works: at
0.3 m and 1280 x 720, the 100 ml amber bottle reads as `SMP-0005`. At 0.45 m the
same labels are about one pixel per module and do not read, which is the
resolution floor above and not something new.

The shelving library is the catalogue too. `simulation/scripts/generate_lab_room.py`
stands every sample the scene does not place by hand on the gantry, once, so
**all 200 samples are in the room, each exactly once**. They are scattered on
purpose: 200 liquids dealt at random over all four shelves, uneven
gaps, varying depth, labels turned up to 25 degrees off the aisle, and the
thirteen hand-placed ones are liquids too. Where a bottle stands
says nothing about what it is, so a detector cannot learn the room by position. Shelved bottles are light stand-in meshes
with the real sticker at half texture resolution (4 px/module). A 1280 x 720
render from about 0.4 m shows six scattered bottles, turned and seen in
perspective. Decoding the whole frame finds two of them; decoding a crop per
bottle, which is what a detector's boxes give and what the reader is built for,
finds four. The two it misses are a bottle at the edge of the frame turned well
away, and a 50 ml flask whose modules are about 1.3 px wide. From 0.6 m and
beyond nothing decodes, the resolution floor again. One thing the scene adds
that the flat tests never had: the shelves have a 20 mm lip, and from a camera
at or below shelf height it hides the bottom of the label on a bottle standing
well back, which for a ladder barcode is its first digits. Geoms are named
`lib_<sample id>_<part>`, so a segmentation render is ground truth for which
sample is where.

Carrying the label corners as pose-model keypoints, so the quad comes from the
network rather than the localiser, is the next step and is not part of this work.

On the placement side, three things are open and each is small:

- **The bench footprint**, so `on_table` stops returning None.
- **A rendered end-to-end check.** The MuJoCo frame conversion is pinned
  against the hand-written back-projection that was measured in simulation,
  but nothing here has yet been run against a frame rendered from this room
  with the camera in the README's MJCF snippet.
- **The real camera's pose**, if a physical GoPro ever replaces the rendered
  one: four markers and `Camera.from_correspondences`, because a bracket is
  never aimed to better than a degree and a degree is 44 mm.
- **Flask dimensions.** `VESSELS` carries the measured agrochemical bottles;
  the five `flask_*` classes the registry knows about have no dimensions
  recorded anywhere yet, so they need `radius` and `height` passed by hand.

## The detector: from a frame to boxes

`labvision/detector.py` is the piece between the frame and everything above:
it says *there is a vessel in these pixels*. The barcode inside the box gives
the identity, `scene.locate` turns the box into a bench position. Nothing was
trained: ten pretrained detectors were benchmarked on real lab photographs and
two were kept. The full write-up is [`docs/BENCHMARK.md`](docs/BENCHMARK.md).

| backend | model | when | CPU, 960 px input |
| --- | --- | --- | --- |
| `world` | YOLO-World large, everyday prompts | best quality; reliable down to 24 px of vessel side | 1.9 s/frame |
| `coco` | YOLO11 small, COCO classes filtered to bottle/cup/glass/vase/bowl | no prompts; most robust on small empty vessels; a laptop | 0.7 s/frame |

For the fixed room camera on the perfumery renders, three more backends came
out of a second benchmark with exact simulator truth, a frozen test split and
an out-of-distribution scene
([`docs/FIXED_CAMERA_BENCHMARK.md`](docs/FIXED_CAMERA_BENCHMARK.md)):
`world-bottles` (YOLO-World large prompted with names of the sample bottles),
`coco26` (YOLO26 small on the same COCO classes, which on these renders finds
twice what YOLO11 small does) and `fixedcam` (YOLO26 nano fine-tuned on
simulator-labelled crops; its weights are made by training, see the write-up).

The network input defaults to the frame's own size, not the usual 640 or 960,
because at this scene's range downscaling pushes the whole bottle kit under
the size floor (next section). A 1080p frame therefore costs about four times
the figures above on a CPU; on a GPU it is still real time.

```python
from labvision.detector import Detector, attach_barcodes
from labvision.scene import VESSELS, default_camera, locate

boxes = Detector("world").detect(frame)          # or Detector("coco")
attach_barcodes(frame, boxes)                     # sets box.barcode when a label decodes
placement = locate(boxes[0].bbox, default_camera(), vessel=VESSELS["bottle_1000ml"])
```

Over a folder of frames, an image or a video, writing overlays and one JSON
line per frame to `results/detect/`:

```bash
python -m labvision.detector ../simulation/out/minihannover_scene --backend both
python -m labvision.detector frames/ --backend coco --barcodes --device cuda:0
```

The label a detector gives is not the identity. A beaker called `cup` is
normal; YOLO-World's "cup" and "glass" prompts are what make empty glassware
appear at all, and lab vocabulary on its own loses half of it. The threshold
per backend is the best-F1 point from the benchmark; override with `--score`.

### The size floor

What decides whether a vessel is found is how many pixels it covers at the
network input, not which model looks at it. Measured by shrinking the
annotated photographs step by step:

| vessel side at the network input | found |
| --- | --- |
| under 24 px | lost (COCO still gets 6 in 10 on tiny cups) |
| 24 to 48 px | a coin toss |
| 48 px and up | 8 to 9 in 10, and no better above 96 px |

`apparent_size_px` predicts that number for a vessel, a range and a camera.
For the scene's camera -- the GoPro in Linear mode, 3.23 m from the bench,
f = 927 px at 1080p -- the bottle kit comes out as follows, side being the
geometric mean of width and height, at the frame's own resolution:

| bottle | 1080p | 4K |
| --- | --- | --- |
| 100 ml | 13 x 28 px, side 19 | side 38 |
| 250 ml | 17 x 38 px, side 25 | side 51 |
| 500 ml | 21 x 47 px, side 32 | side 63 |
| 1 L | 25 x 62 px, side 40 | side 79 |
| 2 L | 33 x 70 px, side 48 | side 97 |

At 1080p only the 2 L bottle reaches the reliable floor and the 100 ml one is
lost outright; every size in between is a coin toss. And that is already at
the native 1920 px input: inferring at 960 halves every side and nothing in
the kit survives, which is why the detector defaults to the frame's own size.
What makes this camera usable, in order of preference, and the test suite
pins the 1080p numbers:

- Capture or render at **4K** and infer at 3840: everything from 250 ml up is
  reliable and the 100 ml bottle becomes a coin toss instead of a loss.
- The **Narrow** digital lens at 1080p, which trades field of view for the
  same gain (`gopro_intrinsics(lens="narrow")`).
- Bring the camera closer; at 1.5 m the 1080p numbers double.

Barcodes are a separate, harder floor: EAN-13 needs about 190 px of label
width to decode, which no overview camera delivers. The fixed camera proposes
a box, the wrist camera reads the label; `attach_barcodes` is for the
close-up frame.

### Measured on rendered bottles: finding them, and sizing them by geometry

`scripts/render_bottles.py` builds the room of `scene.py` in MuJoCo -- the
minihannover worktop, 6 x 1.5 m at z = 0.95, the GoPro at (7, 0, 3) aimed at
its centre -- stands the bottle kit on it in random layouts, and renders
frames with the exact box of every bottle read off a segmentation pass.
`scripts/size_experiment.py` runs a backend on those frames at native
resolution and, for each box, fits every vessel class with
`locate(anchor="fit")` and keeps the smallest residual. Size is therefore a
geometric answer, scored against the truth, never a label from the network.

Two things came out of it.

**`Vessel.silhouette_height_m` is 20 to 30 mm too tall for this kit.** It
stacks the cap on the body (`height + cap - 1 mm`), but the kit's README
seats the cap over the neck (`z = height - cap + 1 mm`), so a closed bottle is
only 1 mm taller than its body: 217 mm for the 1 L, not 242. With the stacked
height the fit called every size one step too small, on exact boxes as much
as on detected ones (0 % right); with the kit's height it is right. The
experiment carries both as `--cap-model scene|kit`, default `kit`. What is
left after that is the shoulder: the topmost pixel is the far edge of the
cap, not of a full-radius rim, which puts the predicted top 2 to 6 px too
high and is what still costs the 2 L bottle.

**Numbers.** 1080p Linear, native 1920 px input, kit cap height, 40 frames
each, `world` / `coco`.

Short bench, 2 x 0.8 m, everything 2.9 to 3.5 m from the camera, 177 bottles:

| bottle | found | size right, of those found | position error, median |
| --- | --- | --- | --- |
| 100 ml | 95 % / 80 % | 100 % / 100 % | 5 mm |
| 250 ml | 96 % / 72 % | 100 % / 100 % | 6 mm |
| 500 ml | 100 % / 78 % | 100 % / 100 % | 7 mm |
| 1 L | 100 % / 89 % | 100 % / 97 % | 9 mm |
| 2 L | 100 % / 87 % | 97 % / 82 % | 12 mm |

The minihannover bench, 2.9 to 4.4 m, 347 bottles, by distance to the camera:

| distance | n | found | size right, of those found |
| --- | --- | --- | --- |
| under 3.0 m | 21 | 91 % / 48 % | 100 % / 80 % |
| 3.0 to 3.5 m | 98 | 87 % / 41 % | 88 % / 95 % |
| 3.5 to 4.0 m | 154 | 58 % / 47 % | 92 % / 92 % |
| over 4.0 m | 74 | 23 % / 49 % | 82 % / 81 % |

So at 1080p the size question is answered whenever the bottle is found: the
geometry is right eight to ten times in ten from any distance, the 2 L
excepted. Finding it is the problem, and it is the size floor again: past
3.5 m YOLO-World loses the small bottles and past 4 m it loses three in four.
COCO finds fewer up close and no fewer far away. Position error, 5 to 18 mm,
is almost all geometry; the exact box gives 5 to 17.

### When rendered frames arrive

1. Render your own: `python scripts/render_bottles.py --frames 40`, with
   `--width 3840 --height 2160` or `--lens narrow` to test the fixes above,
   or put the team's frames next to a `gt.json` in the same format.
2. Score: `python scripts/size_experiment.py <folder> --backend both`.
   Overlays land in `<folder>/overlay_<backend>/`; `--oracle-only` scores the
   geometry alone in seconds.
3. Without ground truth: `python -m labvision.detector <folder> --backend both`.
   The summary prints the median box side; under 48 px the camera is the
   problem, not the model.
4. If both backends fail on frames that pass the size floor, the next step is
   a fine-tune on renderer-labelled frames, not another pretrained model.

### On the perfumery lab: every bottle in the room, from the scene's own cameras

`scripts/render_perfumery.py` renders Eki's `minihannover_scene.xml` as it is,
from its walkthrough cameras and from the vision system's two GoPros: the fixed
`general` one over the bench, and the `wrist` one flown to a random bench
bottle at 0.25 to 0.6 m (`--wrist-range` sets it). Bench layouts are random. The truth is written for
every one of the 200 catalogue bottles with a pixel in view, the loose ones,
the entrance corner and the 187 on the gantry alike: its visible box, its
whole silhouette drawn with nothing in front of it, how much of it is visible,
and whether it stands on the bench, on a shelf or elsewhere. Only the
simulator's state writes that truth; the detector sees the RGB frame alone.
`scripts/perfumery_eval.py` scores a backend on those frames, per set, by
bottle and by apparent size, and names what every false box landed on: a shelf
bottle, glassware, a balance. `scripts/world_prompts.py` tries YOLO-World
vocabularies on the same frames, distractor prompts included.

```
python scripts/render_perfumery.py
python scripts/perfumery_eval.py ../simulation/out/perfumery --backend both --overlays
python scripts/world_prompts.py ../simulation/out/perfumery
```

Measured before the gantry held the catalogue (scene at `663ae2e`, decorative
shelf bottles, a fixed GoPro 1.4 m from the bench): YOLO-World found 91 % of
the bench bottles, 97 % of those 48 px or wider, and COCO found 50 %. From the
walkthrough cameras both found about half, with 79 of 179 bottles under 16 px.
Nine false boxes in ten fell on the shelf library. The worktop filter in
`perfumery_eval.on_worktop`, which back-projects a box's bottom edge onto the
bench plane from the calibrated camera, cut them from 65 to 3.9 per frame on
the walkthrough cameras without losing a bottle, and from 17.5 to 1.8 on the
fixed GoPro, precision 33 % to 82 %. On a CPU, World takes about 7 s per 1080p
frame and COCO 1.3 s.

## From a box to a named bottle: the ring, the wrist and the world state

The fixed camera cannot read a ring: at 3 to 4 m even a 2 L bottle's markers
are a few pixels across. So the vision system works in two passes, and three
modules carry them.

**`labvision/identify.py` --- which sample is in this box.** It reads the
`DICT_4X4_250` markers inside a detector box and a 15 % margin round it, with
the parameters `scripts/wrist_scan.py` measured the ring with, and lets them
vote. Only markers whose centre lies inside the box itself vote, so a
neighbour's ring in the margin does not; the id with the most markers wins and
a tie names nobody, because a guess is a wrong bottle in the gripper. A crop
that reads nothing is read again enlarged (2x, then 3x), but always first at
its own size: on blurred synthetic markers, starting enlarged lost reads it
would have made (11 of 20 against 19 of 20 at 18 px a side).
A crop stops enlarging only when a marker inside the box reads, so a
neighbour's marker in the margin does not end the search. `identify_frame`
reads the whole frame without a detector and groups each id's markers by
distance in the image, so two bottles carrying the same id stay two
identities.

```bash
python -m labvision.identify frame.png                  # whole frame
python -m labvision.identify frames/ --backend world    # detector boxes, then rings
```

**`labvision/perception.py` --- the fixed camera proposes, the wrist confirms.**
Pure functions of frames, boxes and calibrated cameras, so the same code runs
in a render loop, in the console bridge that renders the scene's cameras
itself, or on real GoPros:

1. `propose` places each fixed-camera box on the bench: `scene.locate`'s base
   anchor on the plane z = 0.90 (the scene frame, origin under the bench
   centre), a 25 mm radius because the bottle is not known yet, the caller's
   filter (the worktop test) applied, and boxes within 3 cm merged.
2. `confirm` takes the wrist frame taken looking at a proposal and reads
   every ring near where the proposal projects. Each ring names a bottle, and
   the bottle gives its ring's radius and height (`ring_geometry`, read from
   the label mesh), so `refine_marker` places it on the bench from the ring's
   most frontal marker: the ray through the marker's centre (where its
   diagonals cross) meets the ring's height on the surface, the midpoints of
   its two upright edges span a chord of the ring there, and the axis is one
   radius back along the chord's normal. Going one radius along the view
   instead, as `refine` does when the corners are unusable, left the 1 L
   bottle 17 mm off: with eight markers 45 degrees apart, the most frontal
   one can face up to 22.5 degrees away from the camera. The centre of all
   the ring's markers would not do either: the ones at 45 degrees pull it off
   the facing point, 6.8 mm on a 1 L bottle against 1.5 mm.
3. The ring whose bottle then stands closest to the proposal, within 5 cm,
   names it. Nearness in the image is not enough: from the aisle a bottle
   behind projects right next to the one proposed, and a 50 ml flask 4.5 cm
   behind a 10 ml one shows its ring nearer the aim point than the 10 ml's
   own. When the proposed bottle is hidden from the wrist and only a
   neighbour within 5 cm reads, the record names the neighbour at the
   neighbour's own place, taken from its ring: still a true pair of sample
   and position. The hidden bottle is missed, and `world.one_per_sample`
   drops the neighbour's second sighting.

**`labvision/world.py` --- what the rest of the lab gets.** A
`PerceivedBottle` holds the bench position, the fixed camera's score and the
sample, marker and phase the wrist read. `to_dashboard` turns a list of them
into the console's `PerceivedVessel` records, and a test feeds them to the
bridge's own `perception_state`. The console joins those records to the
vessels it draws by index, so `assign_tracks` pairs each bottle with the
nearest vessel the publisher knows (within 8 cm, one to one) and the record
carries that index:

```python
from labbridge import state as S
from labvision.perception import confirm, perceived, propose
from labvision.world import assign_tracks, to_dashboard

proposals = propose(boxes, general_camera, keep=on_the_worktop)
found = [perceived(p, confirm(wrist_frame_at(p), wrist_camera, target_of(p), rows))
         for p in proposals]
found = assign_tracks(found, {i: xy for i, xy in scene_vessels})
S.perception_state(active_camera="overview", vessels=to_dashboard(found))
```
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

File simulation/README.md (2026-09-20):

# simulation

Physics simulation with [MuJoCo](https://mujoco.readthedocs.io/en/stable/overview.html) and its interactive 3D viewer.

All commands below are run from this directory (`simulation/`).

## Installation

Requires Python 3.10+ (Linux, macOS or Windows). The `mujoco` pip wheel ships the
native engine **and** the OpenGL viewer, so there is nothing else to download.

```bash
./install.sh                 # creates .venv, installs requirements.txt, runs a sanity check
source .venv/bin/activate
```

Manual alternative:

```bash
python3 -m venv .venv && source .venv/bin/activate
pip install -r requirements.txt
python scripts/check_install.py
```

On Debian/Ubuntu the viewer needs the OpenGL runtime: `sudo apt-get install -y libgl1 libegl1`.

## 3D visualizer

```bash
# Interactive viewer that runs the simulation from our script (launch_passive)
python scripts/view_model.py [models/hello.xml]

# Standalone viewer app (drag & drop any MJCF/URDF file onto the window)
python -m mujoco.viewer
python -m mujoco.viewer --mjcf=models/hello.xml
```

On macOS, run passive-viewer scripts with `mjpython` instead of `python`.

Viewer controls: double-click to select a body, Ctrl + right-drag to push it,
Space to pause, Backspace to reset, and the left/right panels toggle rendering options.

## Lab furniture

`minihannover` is our own 6.0 x 1.5 m lab bench (work surface at 0.90 m), generated
for both simulators from a single script:

```bash
python scripts/generate_minihannover.py                       # regenerate the assets
python scripts/view_model.py models/minihannover_scene.xml    # look at it (perfumery lab around the bench, 14 x 5 x 3 m)
```

It ships as MJCF (boxes, and a mesh variant), URDF for the Isaac Lab importer, and an
OBJ interchange mesh. See [`assets/minihannover/README.md`](assets/minihannover/README.md).

The [open-desk variant](assets/minihannover_open/README.md) removes the central
shelving and centers a wider 6 × 2 m desk in the room:

```bash
python scripts/generate_minihannover_open.py
mjpython scripts/view_model.py models/minihannover_open_scene.xml  # macOS
```

What stands on that desk is a **seeded pattern**: one integer fixes how many
flasks there are (10 to 75), how tightly they are packed, whether they sit
scattered, in clusters, in rows or crowded into one end, and which sizes the
crowd is made of. Ten are catalogued, `p01` (16 flasks, spread out) to `p10`
(71 in rows); any other seed works too.

```bash
python scripts/bottle_patterns.py --list              # the ten, at a glance
python scripts/generate_minihannover_open.py --pattern p06   # build that bench
mjpython scripts/view_model.py models/minihannover_open_scene_p06.xml
```

## Robot arm on a rail

The open-desk scene gets a UR10e riding a 6 m linear rail over the bench. The arm
is [Menagerie's](https://github.com/google-deepmind/mujoco_menagerie) UR10e with a
Robotiq 2F-85 on the flange and an eye-in-hand camera beside it. Menagerie is a git
submodule at `third_party/mujoco_menagerie`; init it once (below), or run
`git clone --recursive` when first cloning the repo.

```bash
git submodule update --init third_party/mujoco_menagerie  # UR10e + 2F-85 meshes (shallow submodule)
python scripts/generate_rail_scene.py        # writes the arm model and the scene
mjpython scripts/rail_demo.py --viewer       # watch it run the bench (macOS)
python scripts/rail_reach.py                 # what it can actually reach, in numbers
```

**Why a rail.** The UR10e reaches 1.30 m, the longest arm in Menagerie, and the
desk is 6 x 2 m. Bolted down it covers a 1.30 m disc; on a rail it covers the lot.
`scripts/rail_reach.py` solves top-down IK for the pinch point 20 mm over every
cap on the bench and counts. The table below was taken over the **full** bench
population, which is the interesting case; the scene as shipped is thinned to
`BENCH_VESSELS` and scores 12/12 trivially. Raise that constant to reproduce it:

| Mounting | Vessels reachable |
| --- | --- |
| Rail, free to stand anywhere along the travel | **187/187** (100%) |
| Rail, but the carriage must stand over the cap | 174/187 (93%) |
| Best single fixed station (scanned over the travel) | 98/187 (52%) |

The middle row is the arm's own inner dead zone rather than a reach limit: it
cannot fold onto a point directly under its shoulder, so the carriage stands off
along the rail --- 21 mm on average, 300 mm at worst --- and the misses vanish.
Run `scripts/rail_reach.py` after any change to the bench population: the
counts move with it, the proportions have not.

**Where the rail sits.** The beam runs along y = 0.30, the desk's back edge strip,
with its underside at 1.36 m: 60 mm over the two balances that stand there. The
`general` wall camera looks at the bench from -Y, so a gantry behind the glassware
shadows the back edge instead of the samples. The arm base ends up 0.55 m over the
worktop, roughly the height its own gripper works at, which is what keeps the full
1.30 m available horizontally instead of spending it on the drop to the bench.

### Wrist camera, live

The arm carries an eye-in-hand camera 90 mm to the side of the tool axis and
30 mm under the flange --- on the wrist, just below it. It is a real object in
the scene, not a bare viewpoint: `scripts/generate_wrist_camera.py` builds a
compact GigE machine-vision camera (Basler ace class body, 29 x 29 x 42 mm, C-mount
lens, heat-sink ribs, connectors and cable) on a steel L-bracket bolted to an
adapter plate at the UR10e's 90 mm tool flange, and `generate_rail_scene.py`
attaches it at exactly the pose the MJCF camera has. So the overview shows the
hardware the pictures come from. `scripts/wrist_view.py`
opens the interactive MuJoCo window and streams that camera to a browser tab at
the same time, so the room and the robot's own view sit side by side:

```bash
.venv/bin/mjpython scripts/wrist_view.py                 # sweep the bench
.venv/bin/mjpython scripts/wrist_view.py --mode label    # read one label after another
```

The tab opens by itself at `http://localhost:8008`; the stream is multipart
JPEG off the standard library's HTTP server, so nothing extra is installed. The
MuJoCo window stays interactive throughout, and `[` / `]` cycles its own camera
if you would rather have the wrist view large and the room small.

**The model's origin is the front face of its lens.** Every part of the camera
sits behind that, so none of it can appear in its own picture --- a camera that
sees its own lens hood shows a black crescent on every frame. It is an easy thing
to break by nudging a mount offset, so `generate_rail_scene.py` compiles the scene
and asserts the clearance on every run, and prints it:
`camera: modelled body clears its own lens by 1.0 mm`.

**The camera looks parallel to the tool axis, not converging on it.** That is
deliberate and was a bug first: the gripper sits on the tool axis, so a camera
that converges there aims straight at the back of its own fingers. Parallel puts
the gripper at the frame edge and whatever the camera is aimed at in the middle.

**Reading a label is an aiming problem, not an angle problem.**
`computer-vision/scripts/wrist_scan.py` wants about 0.30 m of standoff and no
more than ~25 degrees of elevation, because the ArUco bars are rings round the
bottle and from above a ring is an arc. But 93 vessels stand about 9 mm apart on
this bench, so a neighbour is usually in the way. Casting a ray at every label
and counting what the camera can actually see:

| Camera elevation | Approaching every vessel from the rail side | Choosing the bearing per vessel |
| --- | --- | --- |
| 8 degrees | 139/187 (74%) | **187/187** |
| 25 degrees | 167/187 (89%) | 187/187 |
| 45 degrees | 178/187 (95%) | 187/187 |

Coming at a vessel from the right side beats climbing above it. `--mode label`
does exactly that: it tries bearings in turn, skips the ones a neighbour blocks,
and takes the first the arm can hold, at the 8 degrees the reader prefers.

Those figures are for the full bench too. On the thinned scene every label is
visible from every bearing, because there is nothing left to hide behind --- so
do not read the shipped scene as evidence the problem went away.

The population is regenerated upstream and has changed size twice already, so
take the proportions rather than the counts. One thing to know if the unbarcoded
reserve stock comes back: the vessel lookup used to match sample ids with
`[A-Za-z0-9-]+`, which does not match `reserve_000`, and silently measured only
the catalogued samples. The blockers were always all present, so the proportions
held, but the counts were quietly halved. It anchors on the part suffix now.

**Motion.** `scripts/rail_demo.py --mode sweep` runs the carriage end to end in a
hand-down scan pose; `--mode visit` picks vessels along the bench and drops the
gripper over each cap in turn. Playback is kinematic by default so it is
deterministic and cannot knock the glassware over; `--mode label` parks the wrist
camera on one label after another; `--physics` drives the position
actuators and steps the simulator instead, where the arm sags up to 4 degrees at
the shoulder under Menagerie's stock gains. Render with `--video out/rail.mp4`
(needs `ffmpeg`) or `--frames <dir>`, from `--camera general`, `carriage` or `eih`.
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

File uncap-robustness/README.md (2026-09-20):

# Uncap-and-pipette robustness

How robust is it for the UR10e hand to take the cap off a bottle with the
iris clamp, pipette from it and put the cap back? This experiment varies
three things:

- the bottle: the six amber bottles of `assets/amber-bottles`, 10–100 ml, each with its own neck and cap;
- how full the bottle is;
- how the arm comes at the bottle.

It runs in MuJoCo with **contact physics**. Nothing is welded:

- **The bottle** is held only by the pads' friction.
- **The cap** is held by the clamp's blades. It rises on a MuJoCo thread (the iris clamp kit's `bottle_cap.xml` recipe): a slide and a hinge coupled by a joint equality, welded to the cap. The thread lets go at the end of its travel, and catches the cap again only when the cap comes back square and centred.

The shipped scene, `simulation/models/iris_pipette_scene.xml`, is not touched. It plays the same sequence with welds.

This directory is self-contained. It reads the rest of the repository and writes nothing outside itself, so `rm -rf uncap-robustness` leaves the repository as it was.

## The reference hand: this is the one that works

**This design is the ground truth for the uncap-and-pipette hand.** It is what
`scene.HAND = 'v3'` builds, and it is what `out/model.html` plays. Earlier
hands are kept only for comparison: the shipped 2F-85 rig (v1) and the 2F-85
with L fingertips and a raised axis (v2), whose results are in
`out/v1_original_rig.csv` and `results/v2_l_fingertips.csv`.

### What it is

| Part | What | Why |
| --- | --- | --- |
| **Gripper** | Compact, ±16 mm about its own axis, drive behind the jaws (`gripper.py`) | The 2F-85 hangs 37.5 mm below its axis and rises 13.5 above; between the table and the clamp's housing that leaves no room under a 57.5 mm cap seat, so the 10, 20 and 30 ml bottles could not be picked at all |
| **Jaws** | One **parabolic cradle**, `y = v - x²/2p`, p = 8 mm, ±22.5 mm wide, 11 convex facets, the same pair for every bottle | A parabola holds any cylinder wider than 2p on two symmetric lines, and the contact walks outwards with the diameter: ±7.5 mm at 43° on the 10 ml, ±22.3 mm at 70° on the 100 ml. The bottle is centred by the pair, not by where the arm put it |
| **Grip** | 400 N drive, liner friction 1.6; the wedge puts 1500–3300 N into 12–23 contacts | It takes 1–4 N·m to turn a bottle in the cradle, against the 0.5 N·m the cap's seating torque applies. With flat pads it took 0.5 |
| **Release** | 25 N while the jaws open, and the hand presses 2 mm past the pick height first | At the full grip the cradle's outer facets sweep off the bottle and drag it back up with the hand |
| **Layout** | Tool axis at cap seat − 21 mm, flange 118 mm behind the jaws | The one rule that fits all six bottles inside both limits |
| **Clamp** | Its own 20 mm lift (`scene.CLAMP_LIFT`), and the iris stop opened from 76° to 80° | Unscrewed, the cap is still 12 mm inside the neck: swinging it out on the hinge's arc dragged it against the neck and tipped the bottle out of the hand. Now the clamp pulls it straight up first. The 80° stop is what reaches the PP18 and PP20 caps |
| **Recap** | Screwed until the torque on the cap says it is seated (0.10 N·m for 0.05 s, at half rate), not by counting turns | The thread catches the cap about 0.4 turns above where it let go, so two turns back leaves it 1–5 mm high |
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

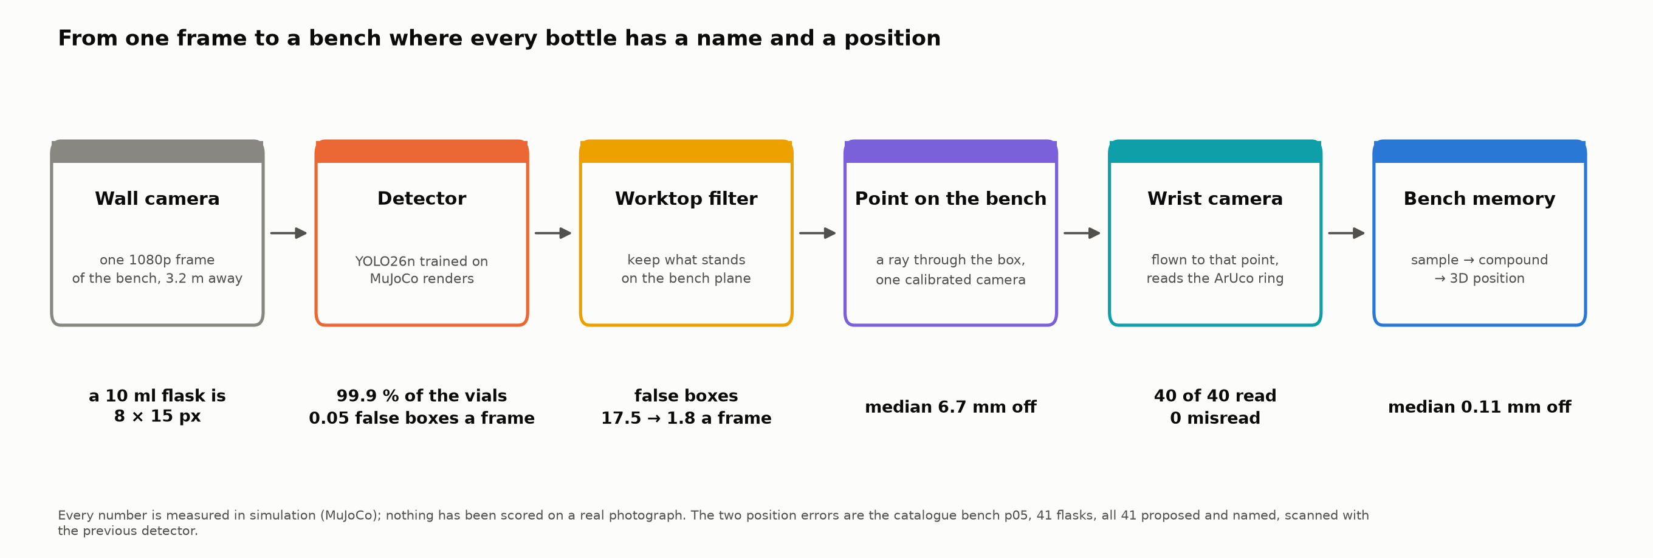
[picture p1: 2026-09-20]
computer-vision/docs/demo/0_overview/pipeline_on_one_slide.png

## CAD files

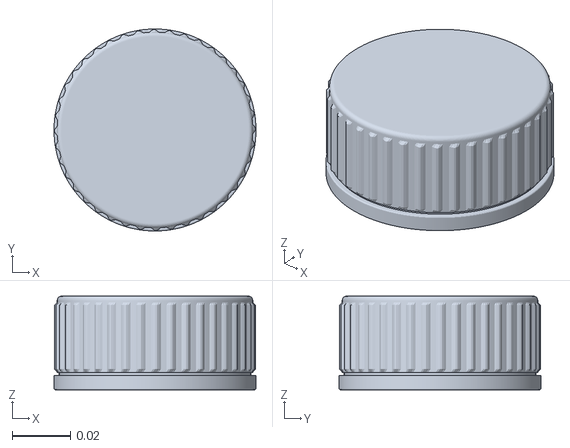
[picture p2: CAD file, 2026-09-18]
simulation/assets/agro_bottles/cap_2l_00.obj
0.0694 x 0.0694 x 0.0322

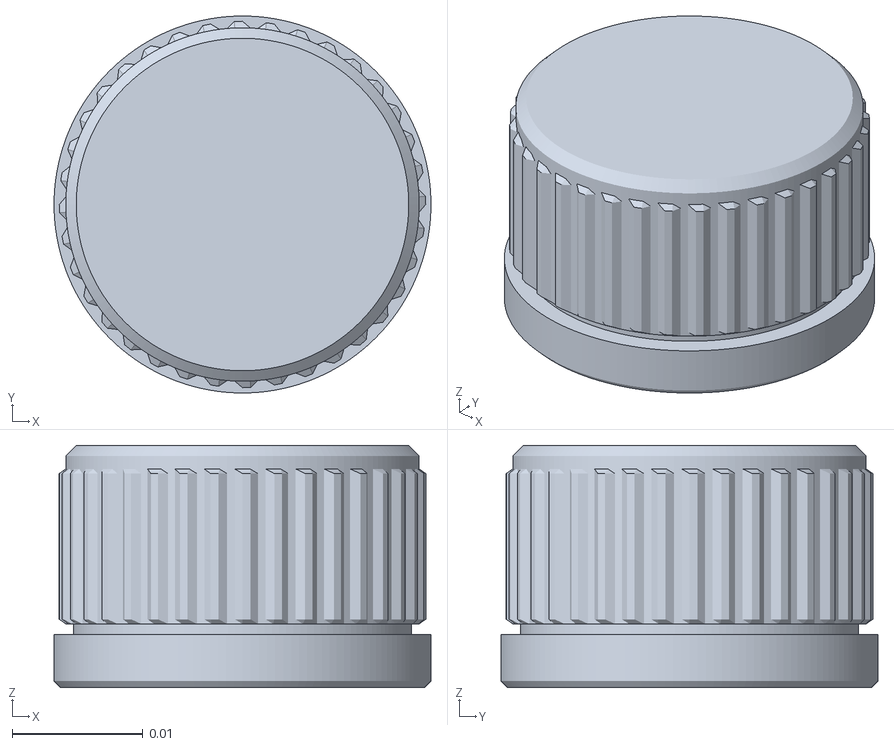
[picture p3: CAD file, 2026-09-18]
simulation/assets/amber_bottles/amber_060ml_00.obj
0.0288 x 0.0288 x 0.0185

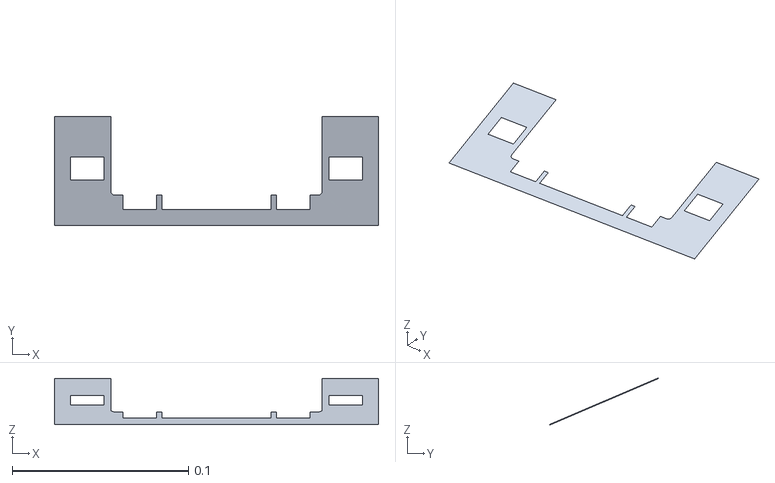
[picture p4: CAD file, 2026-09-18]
simulation/assets/balance/part_02.obj
0.184 x 0.0618 x 0.0264

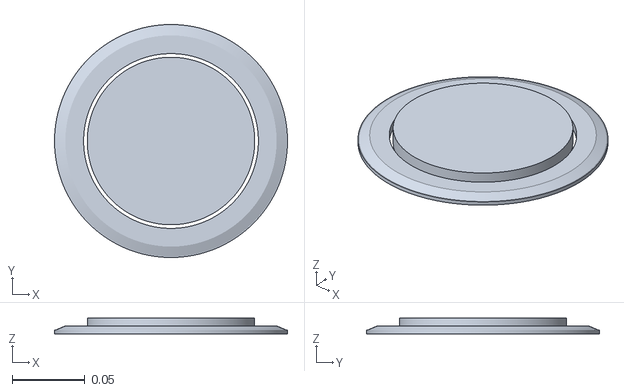
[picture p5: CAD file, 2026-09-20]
simulation/assets/balance_open/part_10.obj
0.16 x 0.16 x 0.0108

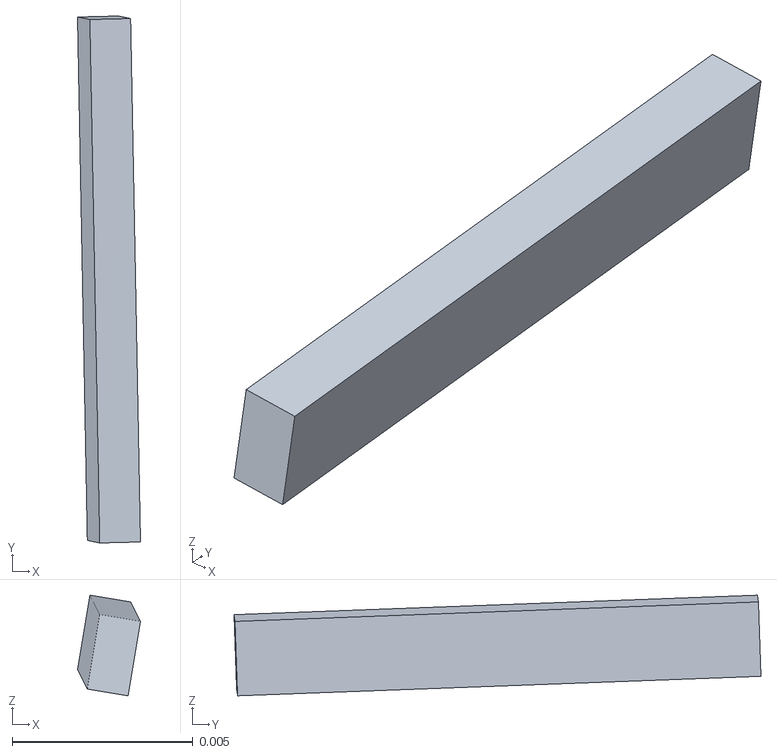
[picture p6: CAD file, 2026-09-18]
simulation/assets/gc_ms/part_17.obj
0.00174 x 0.0146 x 0.00279

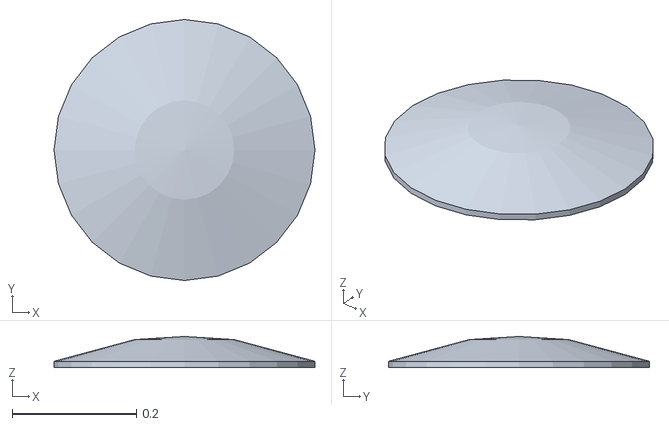
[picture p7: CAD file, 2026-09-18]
simulation/assets/lab_room/meshes/bin_lid.obj
0.42 x 0.42 x 0.05

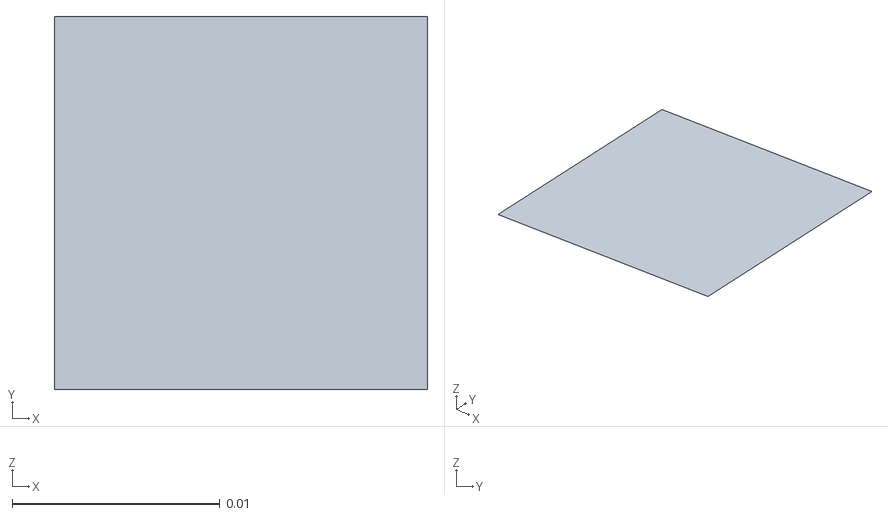
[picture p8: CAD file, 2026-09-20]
simulation/assets/labelled_bottles/meshes/flask_50ml_cap_label.obj
0.018 x 0.018 x 0

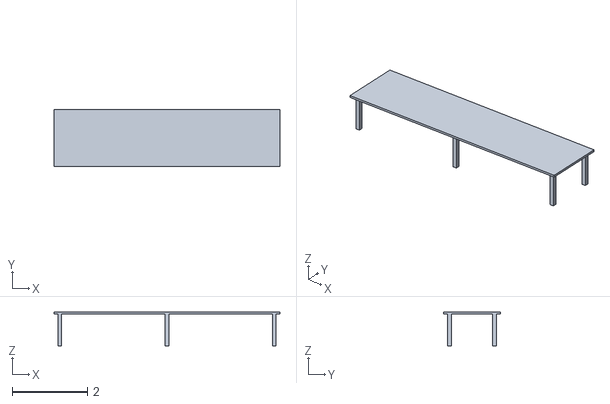
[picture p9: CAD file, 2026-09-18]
simulation/assets/minihannover/minihannover.obj
6.00 x 1.50 x 0.9

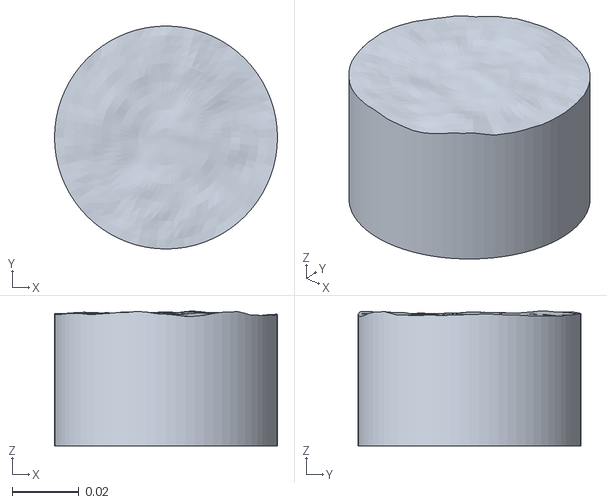
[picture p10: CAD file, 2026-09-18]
simulation/assets/reagent_jars/jar_250ml_02.obj
0.0666 x 0.0666 x 0.0403

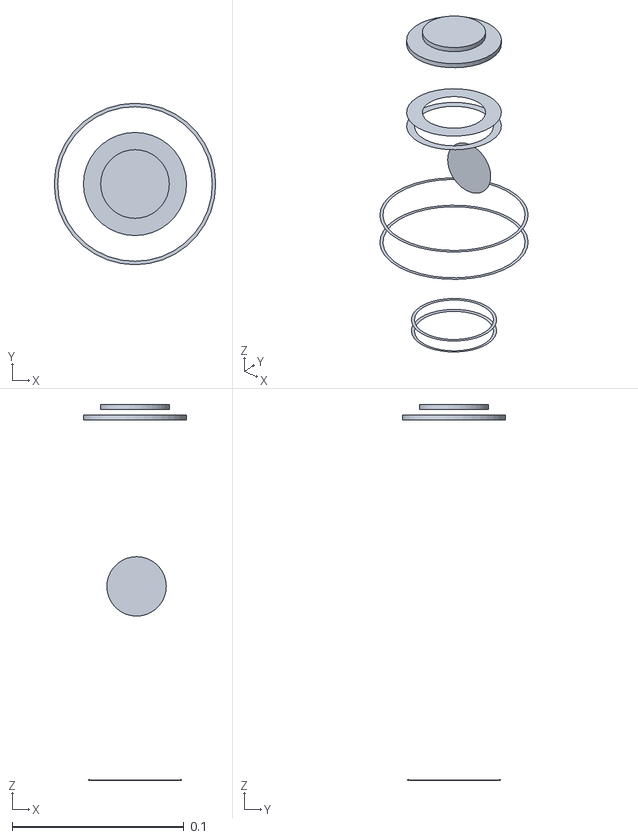
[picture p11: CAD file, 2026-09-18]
simulation/assets/sink/part_03.obj
0.094 x 0.094 x 0.219

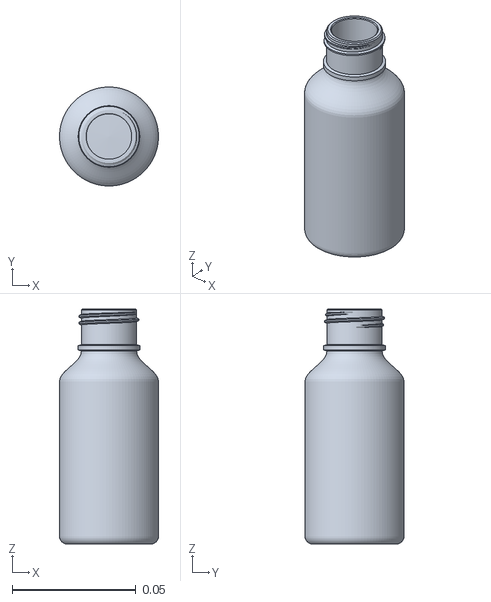
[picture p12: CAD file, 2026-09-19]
simulation/assets/ur10e_iris_pipette/meshes/amber_glass.stl
0.04 x 0.04 x 0.095

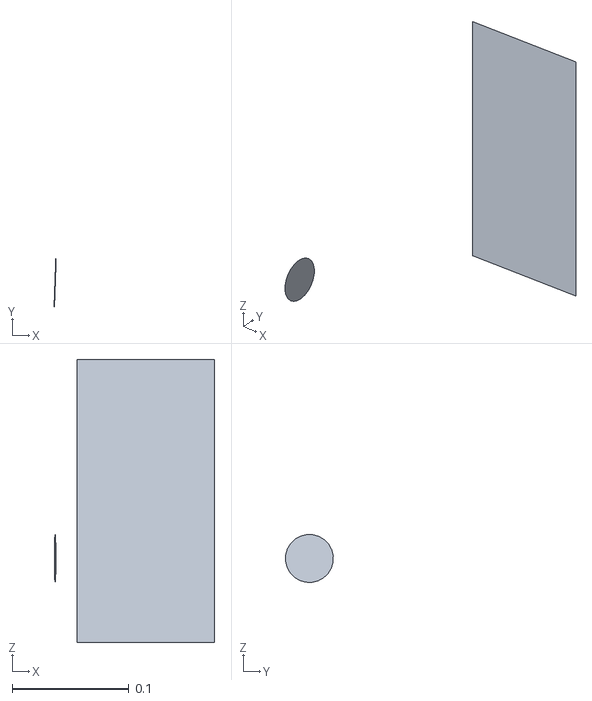
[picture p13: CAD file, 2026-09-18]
simulation/assets/uv_vis_nir/part_12.obj
0.138 x 0.249 x 0.243

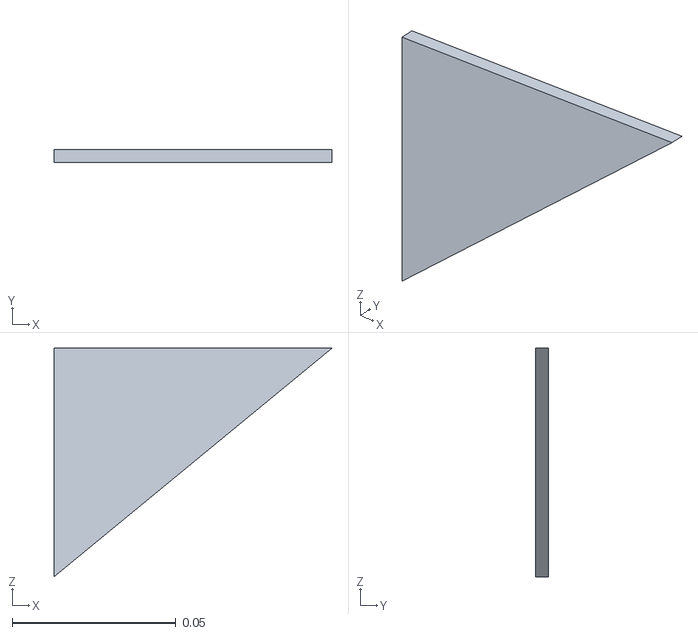
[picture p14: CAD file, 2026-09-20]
simulation/assets/vertical_hand/meshes/col_hand_14.stl
0.085 x 0.004 x 0.0699

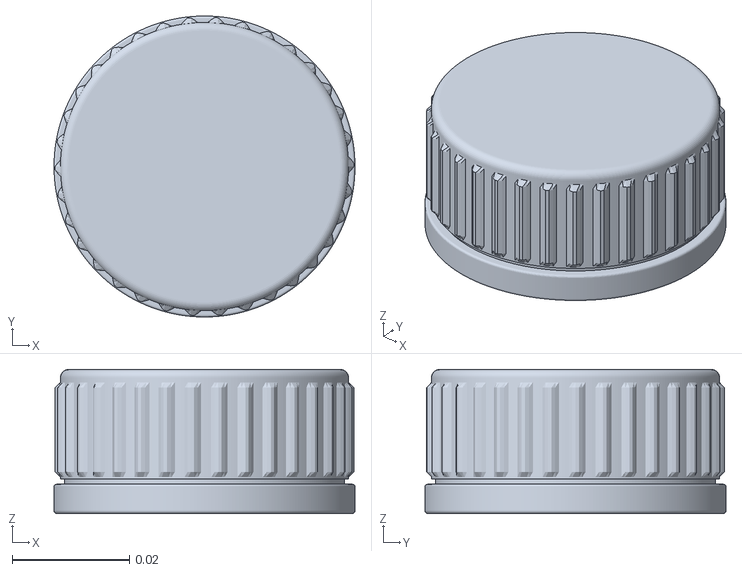
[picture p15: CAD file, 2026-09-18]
simulation/assets/agro_bottles/cap_500ml_00.obj
0.0514 x 0.0514 x 0.0246

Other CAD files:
simulation/assets/amber_bottles/amber_060ml_01.obj
simulation/assets/balance/part_08.obj
simulation/assets/balance_open/part_02.obj
simulation/assets/gc_ms/part_35.obj
assets/agrochemical-bottles/agro_bottles_kit.blend
assets/amber-bottles/amber_bottles_kit.blend
assets/amber-bottles/thread_pair/thread_pair_PP18.blend
assets/amber-bottles/thread_pair/thread_pair_PP20.blend
assets/amber-bottles/thread_pair/thread_pair_PP25.blend
assets/amber-bottles/thread_pair/thread_pair_PP28.blend
assets/pasteur/pasteur_pipette.blend
assets/reagent-bottles/reagent_jars_kit.blend
simulation/assets/agro_bottles/cap_1l_00.obj
simulation/assets/balance/part_00.obj
simulation/assets/balance/part_01.obj
simulation/assets/balance/part_03.obj
simulation/assets/balance/part_04.obj
simulation/assets/balance/part_05.obj
simulation/assets/balance/part_06.obj
simulation/assets/balance/part_07.obj
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

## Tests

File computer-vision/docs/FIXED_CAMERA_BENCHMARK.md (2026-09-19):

# Fixed-camera bottle detection: benchmark

Which detector finds the sample bottles on the bench from the fixed room camera,
measured on simulator renders with exact truth. Two detectors that need no
training are the references (YOLO-World L with bottle prompts, YOLO26s on
COCO); two detectors to fine-tune on simulator-labelled frames were chosen
(YOLO26n and RF-DETR), and the laptop's CPU allowed one epoch of the first.
Everything here was run on 19 September 2026 on the team laptop (Intel
i5-12450H, 8 cores, 16 GB, no GPU).

## Results

**In one line:** a YOLO26n fine-tuned for a single epoch on the CPU, on
simulator-labelled crops, finds bottles on the bench as well as the best
detector that needs no training (YOLO-World L), finds more of the smallest
ones, tells amber from HDPE, costs a fraction of the compute, and is the
most robust to a degraded camera. On a scene it never saw, YOLO-World L holds
up slightly better.

### Main test

Gantry scene, nominal light and camera. The same 30 `test` frames and 334
bottles to find for the three models; worktop region, worktop filter, each
model at the threshold it chose on `val`.

| model | training | AP50 [95 % CI] | AP50:95 | recall [95 % CI] | precision | false boxes / frame | kit AP50 |
| --- | --- | --- | --- | --- | --- | --- | --- |
| YOLO26n fine-tuned | 1 epoch, CPU | 0.864 [0.83-0.89] | 0.639 | **0.886** [0.84-0.92] | 0.836 | 1.93 | **0.88** |
| YOLO-World v2 L, bottle prompts | none | **0.871** [0.84-0.89] | **0.669** | 0.847 [0.81-0.88] | 0.797 | 2.40 | 0.41 |
| YOLO26s COCO | none | 0.687 [0.64-0.73] | 0.548 | 0.722 [0.68-0.76] | **0.873** | **1.17** | - |

The fine-tuned model and YOLO-World L are level on AP50 (the intervals
overlap almost entirely). The fine-tuned one finds more bottles at a higher
precision; YOLO-World draws tighter boxes (AP50:95). On all 60 frames the
fine-tuned model scores 0.835 AP50 [0.81-0.86] and YOLO26s COCO 0.690.

**Kit AP50** asks whether each box also names the right kit. The fine-tuned
model was trained on `amber_bottle` / `hdpe_bottle`; YOLO-World only gets
there through prompts such as "small brown bottle", and mostly does not.

**Cost.** At full CPU speed and on the full frame, YOLO-World L took 6.1 s per
frame and YOLO26s 1.2 s (screening table below). YOLO26n has a quarter of
YOLO26s's operations (5.4 against 20.7 GFLOPs at 640 px). Latencies measured
later in the night are not comparable across models: the CPU was held at a
fifth of its speed and shared with other jobs whose load changed by the hour.

#### Recall by bottle (same 30 frames)

| bottle | YOLO26n fine-tuned | YOLO-World L | YOLO26s COCO | bottles |
| --- | --- | --- | --- | --- |
| amber 10 ml | **76 %** | 62 % | 30 % | 37 |
| amber 20 ml | **84 %** | 77 % | 60 % | 43 |
| amber 30 ml | **93 %** | 86 % | 79 % | 28 |
| amber 50 ml | **86 %** | 81 % | 73 % | 37 |
| amber 100 ml | 93 % | **96 %** | 89 % | 27 |
| HDPE 100 ml | 85 % | **90 %** | 60 % | 40 |
| HDPE 250 ml | **94 %** | 87 % | 74 % | 31 |
| HDPE 500 ml | **95 %** | 87 % | 89 % | 38 |
| HDPE 1 L | 100 % | 100 % | 100 % | 25 |
| HDPE 2 L | 89 % | **93 %** | 89 % | 28 |

#### Recall by apparent size (side of the full silhouette in the frame)

| side | YOLO26n fine-tuned | YOLO-World L | YOLO26s COCO | bottles |
| --- | --- | --- | --- | --- |
| under 16 px | **81 %** | 74 % | 52 % | 77 |
| 16-24 px | **86 %** | 84 % | 69 % | 102 |
| 24-32 px | **95 %** | 92 % | 78 % | 60 |
| 32-48 px | **94 %** | 86 % | 86 % | 50 |
| 48 px and over | 93 % | 93 % | 91 % | 45 |

The gap is where the problem is: under 24 px of side, which is the whole
amber kit up to 50 ml. The 10 ml amber bottle (8 x 15 px) is still missed one
time in four by the best model: that is a camera limit, not a model one (see
*What to do next*).

### Other scene and shifted camera

`test_open` is the open-desk scene, never seen in training; `test_shift` is
the gantry scene under strong light changes with the frame degraded like a
real camera. The table compares the three models on the same first 30
frames of each split.

| split | model | frames | AP50 [95 % CI] | AP50:95 | recall [95 % CI] | precision | false boxes / frame |
| --- | --- | --- | --- | --- | --- | --- | --- |
| `test` | YOLO26n fine-tuned | 30 | 0.864 [0.83-0.89] | 0.639 | 0.886 [0.84-0.92] | 0.836 | 1.93 |
| `test` | YOLO-World L | 30 | 0.871 [0.84-0.89] | 0.669 | 0.847 [0.81-0.88] | 0.797 | 2.40 |
| `test` | YOLO26s COCO | 30 | 0.687 [0.64-0.73] | 0.548 | 0.722 [0.68-0.76] | 0.873 | 1.17 |
| `test_open` | YOLO26n fine-tuned | 30 | 0.675 [0.64-0.71] | 0.500 | 0.870 [0.83-0.91] | 0.662 | 6.83 |
| `test_open` | YOLO-World L | 30 | 0.715 [0.67-0.76] | 0.553 | 0.857 [0.82-0.89] | 0.560 | 10.33 |
| `test_open` | YOLO26s COCO | 30 | 0.500 [0.45-0.55] | 0.422 | 0.770 [0.72-0.82] | 0.486 | 12.50 |
| `test_shift` | YOLO26n fine-tuned | 30 | 0.767 [0.73-0.81] | 0.566 | 0.810 [0.75-0.86] | 0.840 | 1.57 |
| `test_shift` | YOLO-World L | 30 | 0.685 [0.58-0.76] | 0.488 | 0.675 [0.57-0.76] | 0.786 | 1.87 |
| `test_shift` | YOLO26s COCO | 30 | 0.260 [0.17-0.35] | 0.195 | 0.295 [0.19-0.40] | 0.789 | 0.80 |

On all 60 frames the fine-tuned model scores 0.674 AP50 on `test_open` and
0.776 on `test_shift`.

- **Other scene.** All three lose precision, not recall: the open desk puts
  props in view that the gantry scene's camera never showed (the drying rack,
  the sink, more glassware), and they draw false boxes. Here the model with no
  training of ours holds up best: YOLO-World L keeps 0.715 AP50 against the
  fine-tuned model's 0.675, though with more false boxes (10.3 per frame
  against 6.8). Fine-tuning on one scene bought accuracy on that scene, not on
  others; the robot's own scene has to be in the training data.
- **Shifted camera.** Blur, noise and JPEG erase what little an 8 px bottle
  offers. The COCO model collapses (recall 0.72 to 0.30), YOLO-World L drops
  from 0.85 to 0.68, and the fine-tuned model from 0.89 to 0.81, the smallest
  loss of the three. It was trained with light and camera-pose randomisation
  but no blur or noise, so this is the randomisation paying off, and
  degradation augmentation (`fixedcam_crops.py --degrade`) is the obvious next
  step.

### What the examples show

`scripts/fixedcam_examples.py` draws the cached boxes on the worktop band
(green found, magenta missed, red false, grey not required). On the test
frames the most frequent false box is one static object, the glass weighing scoop
beside the right-hand balance, the same one in every frame, plus boxes merging
two touching bottles. Both are the kind of error that hard negatives fix:
render the bench with no bottles and train on it.

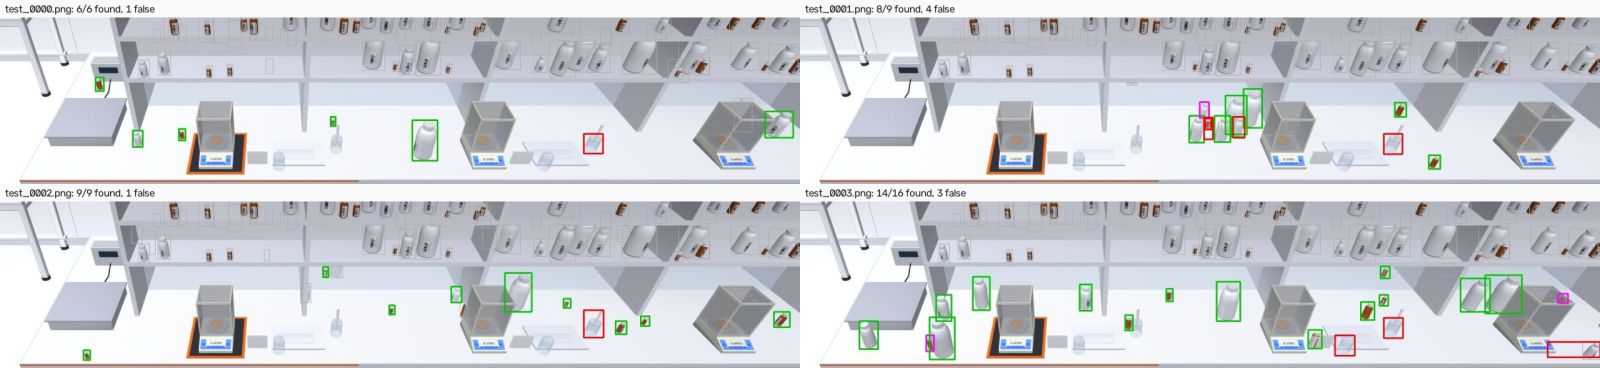
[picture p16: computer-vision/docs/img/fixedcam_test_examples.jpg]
YOLO26n fine-tuned on four test frames


*YOLO26n fine-tuned, first four `test` frames, worktop band only: 37 of 40
bottles found, 9 false boxes, four of them on the scoop.*

### What to do next

1. **Train the fine-tuned model properly, on a GPU.** One epoch on a throttled
   laptop already matches YOLO-World L. 20 to 50 epochs of YOLO26n (or s), with
   bottle-free bench frames as hard negatives and `--degrade 0.5` crops, should
   clear it. The commands above run unchanged on RunPod or Colab.
2. **Train RF-DETR there too** (commands above): the second fine-tuned model
   the plan asked for, and the bet for the change of renderer.
3. **Train on the scene the robot will see.** `test_open` shows a scene change
   costs precision. When the Isaac scene exists, convert its Replicator output
   (`isaac_replicator_to_gt.py`), score it here first with the models as they
   are, then add its frames to training.
4. **Give the 10 ml bottle more pixels.** At 8 x 15 px it is missed one time in
   four by the best model. 4K, the Narrow lens or a mount closer to the working
   area doubles its size; `labvision.detector.apparent_size_px` checks a mount
   before rendering.
5. **Score the full splits** when a normal CPU or a GPU is at hand
   (150 / 100 / 100 frames instead of 30 to 60): the caches resume where they
   stopped.

## The camera and why it is hard

The fixed camera is the scene's `general` GoPro: Linear lens, 1920 x 1080,
60.44 degree vertical field of view, on the aisle wall at (-1.5, -2.9, 3.0),
pitched 39 degrees down. It sees the bench from 3 to 4 m away.

| bottle | size in the frame (median, w x h) | side (sqrt(w h)) |
| --- | --- | --- |
| amber 10 ml | 8 x 15 px | 11 px |
| amber 50 ml | 15 x 25 px | 20 px |
| amber 100 ml | 18 x 31 px | 24 px |
| HDPE 100 ml | 16 x 28 px | 22 px |
| HDPE 500 ml | 26 x 46 px | 35 px |
| HDPE 2 L | 40 x 71 px | 55 px |

Three things make it hard:

1. **Size.** Half the kit is under 24 px of side, the size below which
   pretrained detectors lost vessels in the first benchmark (`BENCHMARK.md`).
   Resizing the frame to a network's usual 640 px input would leave the 10 ml
   bottle at 3 x 5 px, so every model here runs at the frame's own resolution
   or on enlarged tiles.
2. **Look-alikes.** In `minihannover_scene.xml` the gantry above the bench holds
   187 more sample bottles with the same glass, caps and labels. They are real
   bottles, so no prompt or class can reject them. Only geometry can.
3. **White on white.** HDPE bottles are white on a white, glossy worktop.

## What is measured

### Frames

`scripts/fixedcam_dataset.py` renders the `general` camera with MuJoCo and
writes the exact visible box and full silhouette of every sample bottle from
segmentation passes (`render_perfumery.Lab`). Scenes are loaded as committed and
changed only in memory: up to 37 movable bottles (the scene's 7 loose ones plus
3 of every size of both kits) are laid out on free worktop by ray casts, spread
out or in clusters that hide each other.

| split | scene | frames | what changes | used for |
| --- | --- | --- | --- | --- |
| `train` | gantry | 600 | layout, light intensity and colour, worktop tint, camera moved by ~7 cm and ~2 deg | fine-tuning |
| `val` | gantry | 60 | same as train, other seeds | model selection, the operating threshold |
| `test` | gantry | 150 | layout only; nominal light and camera | **the main benchmark** |
| `test_open` | open desk | 100 | layout; a different scene (no gantry, wider desk) never seen in training | generalisation |
| `test_shift` | gantry | 100 | layout, strong light changes, and the frame degraded like a real camera (blur, noise, JPEG, gamma) | robustness, a proxy for Isaac and for a real GoPro |

Every split uses its own seeds, so no layout appears in two splits.

### Scoring

`labvision/evaluation.py`, with tests in `tests/test_evaluation.py`, scores every
model the same way:

- **Must be found:** a sample bottle standing on the bench, at least half
  visible, not cut by the frame border.
- **Ignored:** every other sample bottle in view (on a shelf, mostly hidden,
  clipped). A box on one is neither a hit nor a false positive, like COCO's crowd
  regions.
- **Match:** greedy by score, IoU at least 0.5 with the visible box.
- **AP50** and **AP50:95**: COCO's 101-point interpolated average precision,
  class-agnostic. The detector's job is "there is a bottle here".
- **Operating point:** one score threshold per model, the best F1 on `val`,
  applied unchanged to every test split. Recall, precision and false boxes per
  frame are counted there.
- **Intervals:** 95 % bootstrap over whole frames (1000 resamples).
- **Latency:** median wall time per frame on this CPU, model only.

### The worktop filter

The camera never moves and its pose is known by calibration, so a box can be
checked against the bench without any object pose: cast the bottom centre of
the box onto the worktop plane (z = 0.90 m); keep it if it lands on the worktop
outline and if its pixel height fits a bottle 4.5 to 26 cm tall standing
there. A shelf bottle's base casts far behind the bench, where a bottle of its
pixel height would have to be metres tall. All numbers below are with the
filter; the raw numbers are in `results/fixedcam/*/metrics.json`.

An independent check of the filter on every split kept 100 % of the bottles
that have to be found, so it costs no recall by construction.

### The worktop region

For the same reason every model in the final tables runs on the worktop's band
of the frame only (`+roi` in the model names): the corners of the bench
outline, at the worktop and 26 cm above it, are projected with the camera's
pose, and the frame is cropped to the box they span, at native resolution.
That is half the pixels of the full frame, so it halves the CPU time, and it
is how the detector would run on the robot. The screening table further down
was run on the full frame, before this protocol was fixed.

## Choosing the models

A literature and tooling check (sources at the end) and a screening run on 30
validation frames picked the four.

### Without training

| model | prompts | why considered | outcome |
| --- | --- | --- | --- |
| YOLO-World v2 L | bottle names | the team's current choice | kept |
| YOLO-World v2 L | `labvision.detector.PROMPTS` (everyday vessels) | the current default | prompts cost ~0.3 AP50 here |
| YOLOE-26 L | bottle names | successor of YOLO-World, LVIS 37.8 zero-shot | close second, slower |
| YOLOE-11 L | bottle names | previous YOLOE | below YOLOE-26 |
| YOLOE-26 L | visual prompts from one val frame | "show it an example" | poor: an 8 x 15 px example carries little |
| YOLO11s COCO | classes bottle, cup, vase... | the team's fast choice | poor on these renders |
| YOLO26s COCO | same classes | new COCO model, small-object work in its loss | kept |
| YOLO26l COCO | same classes | larger | not scored: stopped to free the CPU |

Screening numbers: first 30 `val` frames, full frame, worktop filter on,
each model at its own best-F1 threshold on those frames (so these are a
little optimistic; the final tables below take the threshold from `val` and
score other frames). Latency is the median per 1080p frame on this CPU before
it was throttled, and was inflated for the models that ran while other jobs
shared the machine (marked *).

| model | AP50 | AP50:95 | recall | precision | false boxes / frame | s / frame |
| --- | --- | --- | --- | --- | --- | --- |
| YOLO-World v2 L, bottle prompts | **0.853** | 0.642 | 0.770 | 0.892 | 0.80 | 6.1 |
| YOLOE-26 L, bottle prompts | 0.839 | 0.607 | 0.685 | **0.926** | **0.47** | 6.6 |
| YOLO26s COCO | 0.812 | **0.646** | **0.848** | 0.762 | 2.27 | 1.2 |
| YOLOE-11 L, bottle prompts | 0.803 | 0.643 | 0.809 | 0.849 | 1.23 | 8.7* |
| YOLO-World v2 L, everyday prompts (`detector.PROMPTS`) | 0.576 | 0.440 | 0.778 | 0.656 | 3.50 | 12.7* |
| YOLOE-26 L, visual prompts | 0.524 | 0.343 | 0.541 | 0.777 | 1.33 | 10.4* |
| YOLO11s COCO | 0.370 | 0.296 | 0.420 | 0.812 | 0.83 | **1.1** |

What the screening says:

- **Name the samples, not vessels.** The same YOLO-World L goes from 0.58 to
  0.85 AP50 when the prompts describe amber and white plastic bottles instead
  of cups, glasses and beakers, which confirms the prompt experiment on the
  close camera (`world_prompts.py`).
- **YOLO26 is a real step over YOLO11 on tiny objects.** With the same COCO
  classes and no prompts, YOLO26s finds twice the bottles YOLO11s does (0.85 vs
  0.42 recall) at the same cost, which is what its small-target label
  assignment is for. It replaces YOLO11s as the fast reference.
- **YOLOE-26 L** ties YOLO-World L on AP50 with the best precision, but is no
  faster; YOLO-World stays the reference because the team already uses it.
- **Visual prompts do not work at this range**: one example box of 8 x 15 px
  gives the model almost nothing to match.

Not run: SAM 3 (the strongest open-vocabulary model, 53.6 LVIS box AP, but its
weights need manual approval on Hugging Face and it is 848 M parameters, 10 to
30 s per frame on this CPU); LLMDet and MM-Grounding-DINO (strong on LVIS,
seconds per frame on CPU, resize the frame to 800 px, which halves the bottles);
DINO-X and Grounding DINO 1.5/1.6 (cloud API only).

### A model fine-tuned on real lab equipment, tried and rejected

"Chemistry Lab Object Detection" (Roboflow Universe, `chemex/chemistry-lab-object-detection`,
YOLOv12n, 26 real chemistry-apparatus classes including `Reagent_Bottle`,
`Wash_Bottle`, `Weighing_Bottle` and `Nessler_Reagent_Bottle`, self-reported
0.99 mAP50) looked promising: a detector trained on lab bottles specifically,
not everyday vessels or COCO. It ships no downloadable weights, only a hosted
inference API (`labvision`'s benchmark now has `fixedcam_models.RoboflowPredictor`
for this, model key `chemex-bottles`, needs `ROBOFLOW_API_KEY`).

Scored the same way as the other three, worktop filter, `+roi`:

| split | model | frames | AP50 | recall | false/frame |
| --- | --- | --- | --- | --- | --- |
| `test` | chemex-bottles+roi | 30 | 0.000 | 0.000 | 0.00 |

Zero boxes on all 55 `val` and `test` frames scored, at every confidence down
to 0. That is not the whole story, though, and a first pass at explaining it
here (only a real photo of a crowded shelf, misclassified everything) was
wrong to call it pure overfitting: the model does generalise, unevenly, to
real photos it never trained on:

- Three unrelated Wikimedia photos of a plain Erlenmeyer flask (nothing to do
  with Chemex's dataset) are all found as `Conical_Flask` at 0.80-0.90
  confidence. A conical flask has one universal silhouette, and the model has
  genuinely learned it, not memorised its own backgrounds.
- Real photos of an actual reagent bottle are much shakier: one is named
  `Reagent_Bottle` correctly but at only 0.30, another is called `Beaker` at
  0.74. Bottles vary far more in real-world shape than a flask does, and it
  shows: the class we need is the model's weak one even on real photographs.
- Our own bottles, cropped tight and upscaled 2.5x (a fair, generous size, well
  above the reliable floor for other models here), do carry a trace of the
  right answer: `Reagent_Bottle` at 0.01-0.04. That is a further ten-fold drop
  from the already-weak 0.30 on a real bottle photo, which is what a genuine
  sim-to-real gap stacked on an already-weak class looks like — not nothing,
  not the strong signal a flask gets, low enough to disappear under any
  sane threshold.

So: a real, if partial, sim-to-real gap on top of a class the model was never
that confident about to begin with. **Lesson for reading any Universe model's
self-reported mAP: it says nothing about how the model does on your class in
particular, on images outside its own set** — test the exact class you need,
not the model's best one. No further tuning attempted; `chemex-bottles+roi`
stays in `fixedcam_bench.py` for anyone who wants to re-check a newer version.

### Fine-tuned

- **YOLO26** (Ultralytics, January 2026). NMS-free head, no DFL, and STAL, a
  label assignment that enlarges targets under 8 px when choosing anchors,
  which is aimed at exactly this problem. Fastest CPU inference of its family.
  AGPL-3.0, like the rest of Ultralytics.
- **RF-DETR** (Roboflow, ICLR 2026). A DETR with a DINOv2 backbone; the paper
  shows the backbone is what makes it fine-tune well from small datasets. It is
  the bet for the jump from MuJoCo to Isaac's renderer: a foundation backbone
  has seen far more appearance variation than a CNN trained on COCO.
  Apache-2.0. Risk: 16 px patches against 8 px bottles.

Both are trained on the same data: 384 x 384 crops cut from the `train` frames
at native resolution (`scripts/fixedcam_crops.py`), centred near bench bottles,
plus random crops of the worktop region. Every sample bottle in a crop is
labelled `amber_bottle` or `hdpe_bottle`, shelf bottles included: a shelf bottle
is a bottle, and the worktop filter tells bench from shelf.

### Training on this laptop

The laptop has no GPU, and from about 07:00 its CPU was held at a fifth of its
nominal speed (Windows' `% Processor Performance` counter read 20 % with the
machine otherwise idle), so training was cut to what fits:

- **YOLO26n**, COCO weights, 384 px crops, batch 16, AdamW (Ultralytics'
  automatic choice), random scale limited to +-25 % so 8 px bottles do not
  shrink to nothing. **One epoch** was trained (11 min at full speed): the
  next ones ran at 4 min per iteration, about five hours per epoch, and were
  stopped. After that single epoch the model reached 0.92 mAP50 on the
  validation crops (shelf bottles included) and is what the tables call
  "YOLO26n fine-tuned". It is an early checkpoint, not a converged model.
- **RF-DETR Nano** could not be trained here. Unfrozen it took ~17 s per crop on
  three threads; with the DINOv2 encoder frozen (8.3 M of 30 M parameters
  trainable), ~5.6 s per crop while sharing the CPU, which is 40 min per epoch
  of 400 crops at full speed and three hours at a fifth of it. The script is
  ready and was checked end to end on 16 crops (one epoch, checkpoint written).

To train RF-DETR on a GPU (RunPod or Colab, under an hour):

```bash
pip install --no-deps rfdetr==1.10.1
pip install pydantic pyDeprecate supervision peft "pytorch_lightning>=2.6,<3" \
    "torchmetrics[detection]>=1.8.2,<1.9" "faster-coco-eval>=1.7.2" pycocotools scipy \
    torch-hungarian==0.1.0rc0
PYTHONUTF8=1 python runs/fixedcam/train_rfdetr.py \
    ../simulation/out/fixedcam/crops384/coco runs/fixedcam/rfdetr_nano \
    --size nano --epochs 20 --threads 8 --batch 8 --accum 2
python scripts/fixedcam_bench.py run \
    "rfdetr:runs/fixedcam/rfdetr_nano/checkpoint_best_total.pth:nano:384" \
    --splits val,test,test_open,test_shift
```

`rfdetr[train]` is not installed whole on purpose: it pulls `roboflow`, which
downgrades numpy and adds `opencv-python-headless` next to `opencv-python`.
On Windows, `PYTHONUTF8=1` is needed or `rich` fails printing the COCO table.
Drop `--freeze-encoder` on a GPU: the full model is the stronger one.

To train YOLO26n properly on the same GPU, instead of the one-epoch checkpoint
above: `runs/fixedcam/train_yolo26n_gpu.py` restarts from the COCO weights
with mosaic, RAM caching and a full worker pool (no CPU-throttle chunking).
[`../../propuesta_gpu.md`](../../propuesta_gpu.md) specs the hardware
(Ampere/Ada, >= 24 GB VRAM, driver 570/580); provision it per
[`../../simulation/runpod-render.md`](../../simulation/runpod-render.md) §1
using one of that proposal's recommended cards (`NVIDIA A40`, `NVIDIA L40S`,
`NVIDIA RTX A6000` or `NVIDIA GeForce RTX 4090`), then:

The script keeps the same relative layout as this repo (`../yolo26n.pt`,
`../simulation/out/...`), so mirror that under one remote directory:

```bash
ssh -i "$SSHK" -p "$PORT" -o StrictHostKeyChecking=accept-new root@"$IP" \
    'mkdir -p /root/repo/computer-vision/runs/fixedcam /root/repo/simulation/out/fixedcam'
scp -i "$SSHK" -P "$PORT" runs/fixedcam/train_yolo26n_gpu.py \
    root@"$IP":/root/repo/computer-vision/runs/fixedcam/
scp -i "$SSHK" -P "$PORT" ../yolo26n.pt root@"$IP":/root/repo/yolo26n.pt
scp -i "$SSHK" -P "$PORT" -r ../simulation/out/fixedcam/crops384 \
    root@"$IP":/root/repo/simulation/out/fixedcam/
ssh -i "$SSHK" -p "$PORT" -o ServerAliveInterval=30 root@"$IP" \
    'cd /root/repo/computer-vision && pip install -q ultralytics && python runs/fixedcam/train_yolo26n_gpu.py'
scp -i "$SSHK" -P "$PORT" -r \
    root@"$IP":/root/repo/computer-vision/runs/fixedcam/yolo26n_384_gpu ./runs/fixedcam/
```

Copy the resulting `weights/best.pt` to `runs/fixedcam/yolo26n_fixedcam.pt` and
rerun `fixedcam_bench.py run "ft:runs/fixedcam/yolo26n_fixedcam.pt+roi"` to
compare against the CPU checkpoint's 0.864 AP50 (`compare_test30.md`).

## Running it

From `computer-vision/`, with the repository's virtual environment:

```bash
# 1. Frames and truth (about 1.5 s per frame)
python scripts/fixedcam_dataset.py --splits train,val,test,test_open,test_shift

# 2. Training crops, YOLO and COCO layouts
python scripts/fixedcam_crops.py --size 384 --per-frame 2 --random-share 0.5 \
    --out ../simulation/out/fixedcam/crops384
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

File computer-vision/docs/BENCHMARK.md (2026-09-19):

# Detector benchmark: which pretrained model finds vessels in a frame

Question: where are the vessels in the fixed camera's image? The label does not matter, identity comes from
the collar tag (the team later moved to EAN-13 barcodes; see `README.md`). Measured on 18 and 19 September
2026 with pretrained models as downloaded, without training anything, on 5 real laboratory photographs with
11 hand-annotated flasks. Machine: 12-thread CPU, no GPU. The overlays for every run are written to
`results/bench/`, which is gitignored.

The five photographs (Wikimedia Commons downloads), the hand-made boxes and the scripts that ran the
benchmark are local tooling and are not in the repository; this document is the record.

## Decision

Two backends are ready in `labvision/detector.py`, selected by argument. They return `BBox` from
`labvision.scene`, so `scene.locate` consumes them as is:

| backend | model | what for | CPU at 960 px |
|---|---|---|---|
| `world` | YOLO-World large, everyday prompts | best quality: finds all 11 flasks, reliable from a 24 px side. Machine with GPU | 1.9 s/frame |
| `coco` | YOLO11 small, filtered COCO classes | no prompts, the most robust with small, stacked empty beakers. Laptop without GPU | 0.7 s/frame |

Inference resolution **960 px**. At 640 the 100 ml beaker is 35 px from 80 cm and gets lost.

Discarded: Grounding DINO and OWLv2 (9 to 13 s/frame on CPU; OWLv2 draws one box per shelf instead of
one per flask), FastSAM and YOLOE without prompts (a lot of background noise), YOLO-World medium (worse
than small and large, with no clear explanation), Roboflow models fine-tuned on other people's laboratories
(small dataset, no guarantee of transferring to renders).

## Main table (640 px unless stated)

Class-agnostic evaluation: any box with IoU overlap ≥ 0.4 against a reference flask counts.
Recall and precision at each model's best-F1 confidence threshold.

| model | prompts | ms/frame | AP | recall | precision | boxes in the cabinet (~60 vessels) |
|---|---|---|---|---|---|---|
| yolov8l-world | everyday | 1090 | 0.92 | 1.00 | 0.85 | 70 |
| yolov8s-world | everyday | 470 | 0.89 | 0.82 | 1.00 | 21 |
| yoloe-11m | laboratory | 1570 | 0.87 | 1.00 | 0.73 | 6 |
| yolov8l-world | laboratory | 1090 | 0.86 | 0.91 | 0.91 | 13 |
| owlv2-base | everyday | 9100 | 0.80 | 0.82 | 0.75 | 9 |
| yolov8s-world @960 | laboratory | 481 | 0.74 | 0.82 | 0.69 | 31 |
| yoloe-11s @960 | laboratory | 549 | 0.74 | 0.82 | 0.64 | 15 |
| yoloe-11s | everyday | 375 | 0.71 | 0.82 | 0.53 | 46 |
| yolov8s-world | laboratory | 470 | 0.71 | 0.64 | 1.00 | 10 |
| yolo11s-coco | (fixed) | 419 | 0.61 | 0.73 | 0.67 | 86 |
| yolo11s-coco @960 | (fixed) | 724 | 0.60 | 0.73 | 0.67 | 94 |
| grounding-dino-t | everyday | 13465 | 0.58 | 0.82 | 0.56 | 10 |
| yoloe-11s-pf (no prompts) | | 565 | 0.47 | 0.55 | 0.55 | 56 |
| fastsam-s | | 480 | 0.39 | 0.46 | 0.56 | 2 |

Latencies measured with the machine otherwise idle; they vary ±30 % under other loads.

## Prompts matter more than the model

"Laboratory" prompts: glass flask, erlenmeyer flask, beaker, glass bottle, vial, laboratory glassware.
"Everyday" prompts: cup, drinking glass, glass, bottle, jar, beaker, glass flask, vial.

Open-vocabulary models score each region against the text embedding of the prompt. "cup" and "glass" have
millions of examples in their training data; "beaker" a few dozen. An empty beaker scores 0.4 against "cup"
and 0.08 against "beaker": with a 0.1 threshold it only appears with the former. With the everyday prompts
YOLO-World large goes from 13 to 70 boxes in the cabinet and from 0.91 to 1.00 recall. Rule: short, everyday
nouns, with synonyms; class-agnostic NMS merges the duplicates. "Bin" classes such as hand, robot arm or
table can be added to absorb false positives and then be discarded.

YOLO11 COCO uses no prompts: its 80 classes are fixed. "cup" and "bottle" are among them, very well
trained, and that is why it is the best with small empty beakers. It fails with round-bottom flasks, which
look like none of its classes, and its list cannot be extended without retraining.

## Size and distance

Each annotated photo was shrunk to 7 scales inside a canvas of its own size, simulating the camera moving
further and further away. Fraction of flasks found by flask side in pixels at the network input, pooled
over the 640, 960 and 1280 resolutions:

| model | 12-24 px | 24-48 px | 48-96 px | > 96 px |
|---|---|---|---|---|
| yolov8l-world (everyday) | 12 % | 62 % | 89 % | 87 % |
| yoloe-11s (everyday) | 34 % | 44 % | 82 % | 90 % |
| yolo11s-coco | 62 % | 54 % | 85 % | 80 % |
| yolov8s-world (everyday) | 16 % | 42 % | 74 % | 68 % |

Rule: **reliable from a 48 px side at the network input**; between 24 and 48 it is a coin toss; below
24 it is lost, except COCO with tiny beakers. YOLO-World large at 960 is the only one reliable from 24 px.

Apparent size in the design's fixed camera (1280×720, 60° horizontal field of view) at 80 cm from the table:

| flask | net at 640 | net at 960 | net at 1280 |
|---|---|---|---|
| vial 2 cm | 14 ✗ | 21 ✗ | 28 ✗ |
| test tube 1.5 cm | 10 ✗ | 16 ✗ | 21 ✗ |
| beaker 100 ml, 5 cm | 35 ✗ | 52 ✓ | 69 ✓ |
| beaker 250 ml, 7 cm | 48 borderline | 73 ✓ | 97 ✓ |
| bottle 500 ml, 7.5 cm | 52 ✓ | 78 ✓ | 104 ✓ |
| erlenmeyer 250 ml, 8.5 cm | 59 ✓ | 88 ✓ | 118 ✓ |

Consequences: at 80 cm infer at 960; at 120 cm 1280 would be needed; vials and test tubes do not show up
from the fixed camera at any reasonable height, they belong to the wrist camera or to a rack with a tag.

**Warning for the team's scene.** `labvision/scene.py` sets the camera as a GoPro in Linear mode at 1080p
(f = 927 px, 60° vertical field of view), on the wall 3.23 m from the table. Size of the kit's HDPE bottles
(`scene.VESSELS`) in the frame, side = square root of width times height:

| bottle | 1080p | 4K |
|---|---|---|
| 100 ml | 13×28 px, side 19 | side 38 |
| 250 ml | 17×38, side 25 | side 51 |
| 500 ml | 21×47, side 32 | side 63 |
| 1 L | 25×62, side 40 | side 79 |
| 2 L | 33×70, side 48 | side 97 |

At 1080p only the 2 L reaches the 48 threshold and the 100 ml is lost. And that is inferring at the native
1920 resolution: if the network works at 960, everything is halved and the whole kit disappears. That is why
the detector defaults to the frame size, not 960. Fixes: record or render at 4K, with which everything from
250 ml up is reliable, or use the Narrow lens at 1080p, or move the camera closer. `detector.apparent_size_px`
computes the size for any camera and distance before rendering anything.

With many small empty beakers (cabinet shrunk to half, 960 px): COCO 89 boxes, YOLOE small 68,
YOLO-World large 33, YOLO-World small 7.

## Limitations

Real photos from the side, not top-down renders. 11 references: each flask moves recall by 9 %. Minimum
overlap 0.4 because the boxes were annotated by eye. What carries over to Isaac is the size in pixels:
measure how many pixels a beaker takes up in a render and you know which band you are in.

## When Isaac frames arrive

The team's renders come from `../simulation/scripts/render_dataset.py` (MuJoCo, `../simulation/out/<scene>/`)
or from AutoBio on RunPod (`../simulation/runpod-render.md`). Steps:

1. Put the frames in a folder, e.g. `data/isaac/rgb/` (PNG or JPG). If there are labels, in
   `data/isaac/labels/` as `<frame>.txt` in YOLO format (class cx cy w h, normalised) or `<frame>.json`
   with `{"boxes": [[x1,y1,x2,y2], ...]}`.
2. See what each backend finds, with overlays in `results/detect/` (from `computer-vision/`):
   ```
   python -m labvision.detector ../data/isaac/rgb --backend both --barcodes
   ```
   The summary line prints the median side of the boxes in pixels: if it is below 48, the problem is the
   camera or the resolution, not the model.
3. With labels, measure properly and regenerate the report:
   ```
   python scripts/isaac_to_gt.py data/isaac/rgb --labels data/isaac/labels --out data/isaac/gt.json
   python scripts/bench_detectors.py --images data/isaac/rgb --gt data/isaac/gt.json --models yolov8l-world,yolo11s-coco --imgsz 960 --out results/bench_isaac
   python scripts/bench_report.py --bench results/bench_isaac --out results/bench_isaac/report --scale none
   ```
4. If a render looks different from the real photos and both backends fail, it is time for fine-tuning
   with renderer-labelled frames, not for trying more models.

## Size experiment at 1080p on renders (19 September)

`scripts/render_bottles.py` builds in MuJoCo the scene from `scene.py` with the 6 × 1.5 m minihannover
table and the bottle kit at random positions, and produces exact boxes by segmentation.
`scripts/size_experiment.py` runs the detector at native resolution and classifies the size of each box by
geometry: it fits the five classes with `locate(anchor="fit")` and the one with the lowest residual wins.

**Finding for Nacho:** `Vessel.silhouette_height_m` adds the cap height to the body, but in the kit the cap
wraps around the neck and only adds 1 mm (the closed 1 L measures 217 mm, not 242). With its height the
geometry classified everything one size down, even with exact boxes. With the kit's height it gets it right.
The script carries both as `--cap-model scene|kit`. What remains after that is the shoulder: the cylinder
model puts the top edge 2 to 6 px too high, and that is what the 2 L still struggles with.

Short table, everything between 2.9 and 3.5 m, 177 bottles, YOLO-World large / COCO:

| bottle | found | correct size among those found | position error |
|---|---|---|---|
| 100 ml | 95 % / 80 % | 100 % / 100 % | 5 mm |
| 250 ml | 96 % / 72 % | 100 % / 100 % | 6 mm |
| 500 ml | 100 % / 78 % | 100 % / 100 % | 7 mm |
| 1 L | 100 % / 89 % | 100 % / 97 % | 9 mm |
| 2 L | 100 % / 87 % | 97 % / 82 % | 12 mm |

6 m table, from 2.9 to 4.4 m, 347 bottles, by distance to the camera:

| distance | n | found | correct size among those found |
|---|---|---|---|
| under 3.0 m | 21 | 91 % / 48 % | 100 % / 80 % |
| 3.0 to 3.5 m | 98 | 87 % / 41 % | 88 % / 95 % |
| 3.5 to 4.0 m | 154 | 58 % / 47 % | 92 % / 92 % |
| over 4.0 m | 74 | 23 % / 49 % | 82 % / 81 % |

Conclusion: at 1080p the size can be told apart whenever the bottle is found; what fails at a distance is
finding it. Past 3.5 m YOLO-World loses the small ones and past 4 m it loses three out of four. The fixes
are those of the previous section: 4K, Narrow lens or a closer camera.

Scripts: `scripts/bench_detectors.py` (table and overlays), `scripts/bench_scale.py` (size and distance),
`scripts/bench_report.py` (HTML page) and `scripts/isaac_to_gt.py` (label converter) are the local tooling
mentioned at the top, not in the repository. `scripts/render_bottles.py` and `scripts/size_experiment.py`
(the size experiment) are.

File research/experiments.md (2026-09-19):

# Experiments — baseline and innovative

> **Context.** This document turns the policy-family shortlist (ACT, Diffusion Policy,
> SmolVLA, π0.5/GR00T/X-VLA, RL, world models) into concrete experiments for the MAFER
> challenge, grounded in what the vault actually contains and what the repository can
> actually run today. Platform decision: **Isaac Lab on remote NVIDIA GPUs**. Local
> hardware is not a constraint.
>
> Written in English per `AGENTS.md`, unlike the Spanish vault documents `01`–`04`.
> Not linked from `Home.md`, which is generated by `tools/build_vault.py` and would
> overwrite the edit.

---

## 0. Three corrections to the shortlist

The shortlist is sound generic advice. Three project-specific facts reorder it.

### 0.1 There is no MDP yet

`simulation/models/minihannover_scene.xml` compiles with **`nu = 0`** — no arm, no
actuator, no gripper, no sites, no sensors. 962 geoms of set dressing and 7 free-floating
amber bottles. The only commandable robot anywhere in the repository is AutoBio's
(`nu = 7`, ALOHA / UR5e), pinned to **MuJoCo 3.3.0** and Linux-only.

Choosing Isaac Lab means not inheriting AutoBio's robot, **nor its scripted experts, nor
its `task.check()` success oracle**. Those have to be built. That is the critical path —
not model selection. Everything below is gated on §1.

### 0.2 Isaac Lab is the right call, including for a reason easy to miss

`simulation/tools/convert_glb.py` discards UVs and textures; `assets/README.md` states
that labels render white. So the **200 barcode-labelled GLBs cannot appear in a MuJoCo
scene at all**. USD import preserves them.

Isaac Lab is therefore a *prerequisite* for any experiment using the project's most
distinctive asset, not merely a performance preference. Separately, Orbit
(`Content/Sources/Mittal2023orbit - ...md`) reports **50,000–75,000 FPS at 2048 envs**,
which is what promotes RL from last place.

### 0.3 The ACT-vs-Diffusion comparison has already been run, on Isaac Sim, on lab tasks

`Content/Sources/Li2025labutopia - LabUtopia High-Fidelity Simulation and Hierarchical.md`
benchmarks ACT, Diffusion Policy and π0 on Franka Panda lab manipulation in Isaac Sim.

| Task | ACT | Diffusion Policy |
| --- | --- | --- |
| Level-2 Heater Beaker | **86.7 %** | 25.0 % |
| Level-2 Operate Drawer | **73.3 %** | 10.0 % |
| Level-2 Stir with GlassRod | **55.0 %** | 10.0 % |
| Level-3 Transport Beaker, ID → OOD | held 65.0–96.7 % | 67.5 → **15.0 %** |

Diffusion Policy *"frequently stalled, e.g. pausing during Heater Beaker's final action
until timeout."* And, verbatim: *"Fine-tuned pretrained VLA models did not consistently
outperform models trained from scratch on Level-3 tasks."*

This contradicts two of the shortlist's premises in exactly this domain: that Diffusion
Policy is the more robust choice under randomization, and that large pretrained VLAs
generalize best. Plain Diffusion Policy stays in the plan as a **control**, not as a step up.

### 0.4 Revised order of practicality for this project

| Rank | Family | Why the change |
| --- | --- | --- |
| 1 | **ACT** | Unchanged, and now with direct Isaac-Sim lab evidence (LabUtopia) including the best OOD retention |
| 2 | **Equivariant Diffusion Policy** | Absent from the original shortlist; it is the vault's actual edge and the bottles are best-case geometry |
| 3 | **RL refinement** | Up from #5 — Isaac Lab's parallel envs are what make it cheap |
| 4 | **SmolVLA** | Retained for language/identity conditioning only; note §5.2 |
| 5 | **Plain Diffusion Policy** | Demoted to control arm for B4 / I2 |
| 6 | **π0.5 / GR00T / X-VLA** | Demoted: the ready-made LIBERO/RoboCasa fine-tunes are robosuite/MuJoCo, and LabUtopia found fine-tuned VLAs did not consistently win |
| 7 | **World models** | Agreed — do not start |

---

## 1. P0 — the gate (a prerequisite, not an experiment)

Isaac Lab + stock Franka Panda + the six agrochemical vessels as USD.

**Task `BottleToBalance`.** Grasp the named bottle; place it on the analytical balance pan.

- **Expert**: Isaac Lab `DifferentialIKController`.
- **Success**: bottle centroid within pan radius, **held continuously for 2 s** — LabUtopia's
  definition, adopted verbatim so the numbers are comparable.
- **Randomization**: **15 cm × 15 cm** placement region — also LabUtopia's, same reason.
- **Cameras**: `general` + `wrist`, both already mounted and pinned to `labvision`'s
  `default_camera()` — GoPro Linear, 1080p, `fovy` 60.44. Port both to the Isaac Lab scene
  unchanged so CV's measurements carry over. `wrist` currently rides a mocap body; §1 is what
  turns it into an actual wrist camera.

**Why this task.** SO(2)-symmetric cylinders on a plane (equivariance applies); two valid
grasp approaches (multimodality applies); 200 barcode identities (language applies); and a
success oracle that needs no new physics.

**Exit criterion: 200 scripted demonstrations at ≥ 95 % expert success.**

> **Known blocker.** `simulation/assets/balance/balance.xml` is visual meshes
> (`contype=0, density=0`) plus one 6 kg collision box — **no joint, no pan, no weight
> sensor**. Placement is checkable; *weighing is not*, until a force sensor is authored.
> Any "weigh N grams" task is therefore out of scope until that lands.

---
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

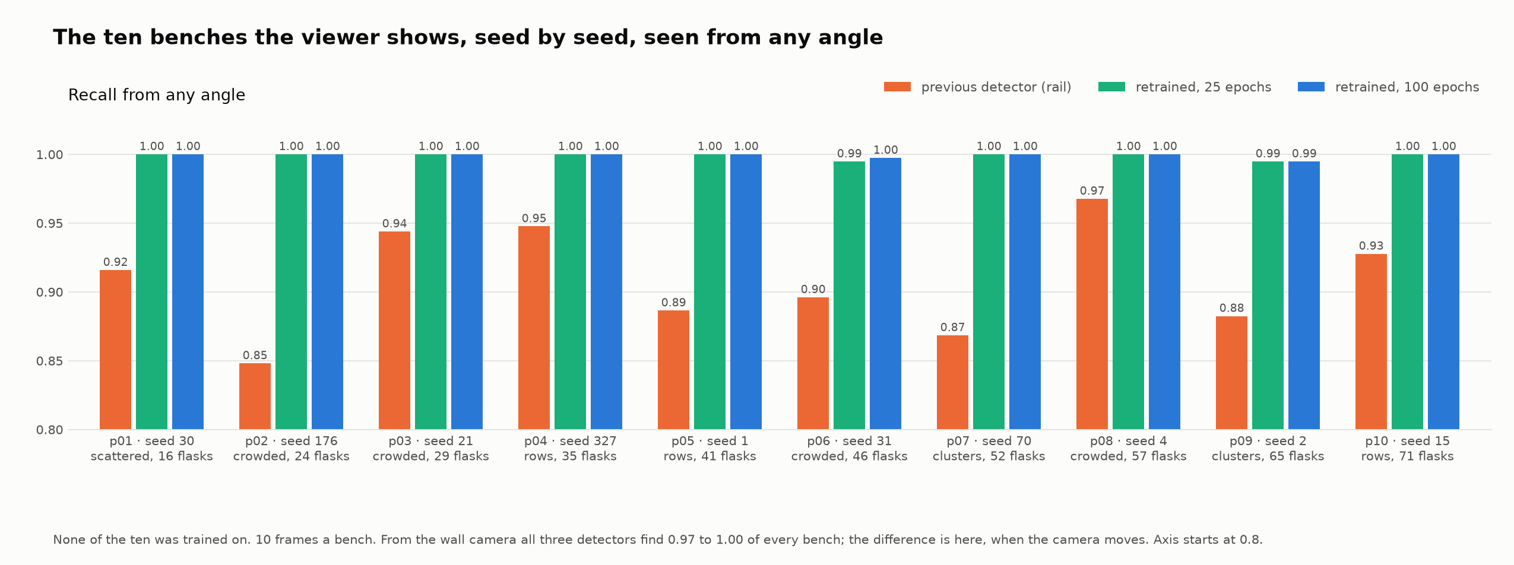
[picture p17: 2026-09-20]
computer-vision/docs/demo/3_results/demo_benches_by_seed.png

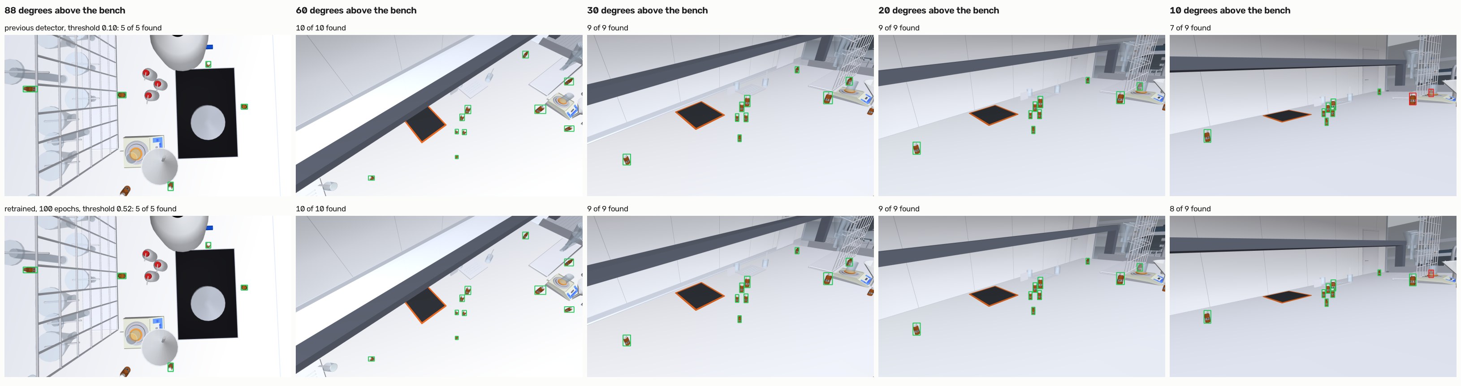
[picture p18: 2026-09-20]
computer-vision/docs/demo/3_results/examples_as_the_camera_tilts.jpg

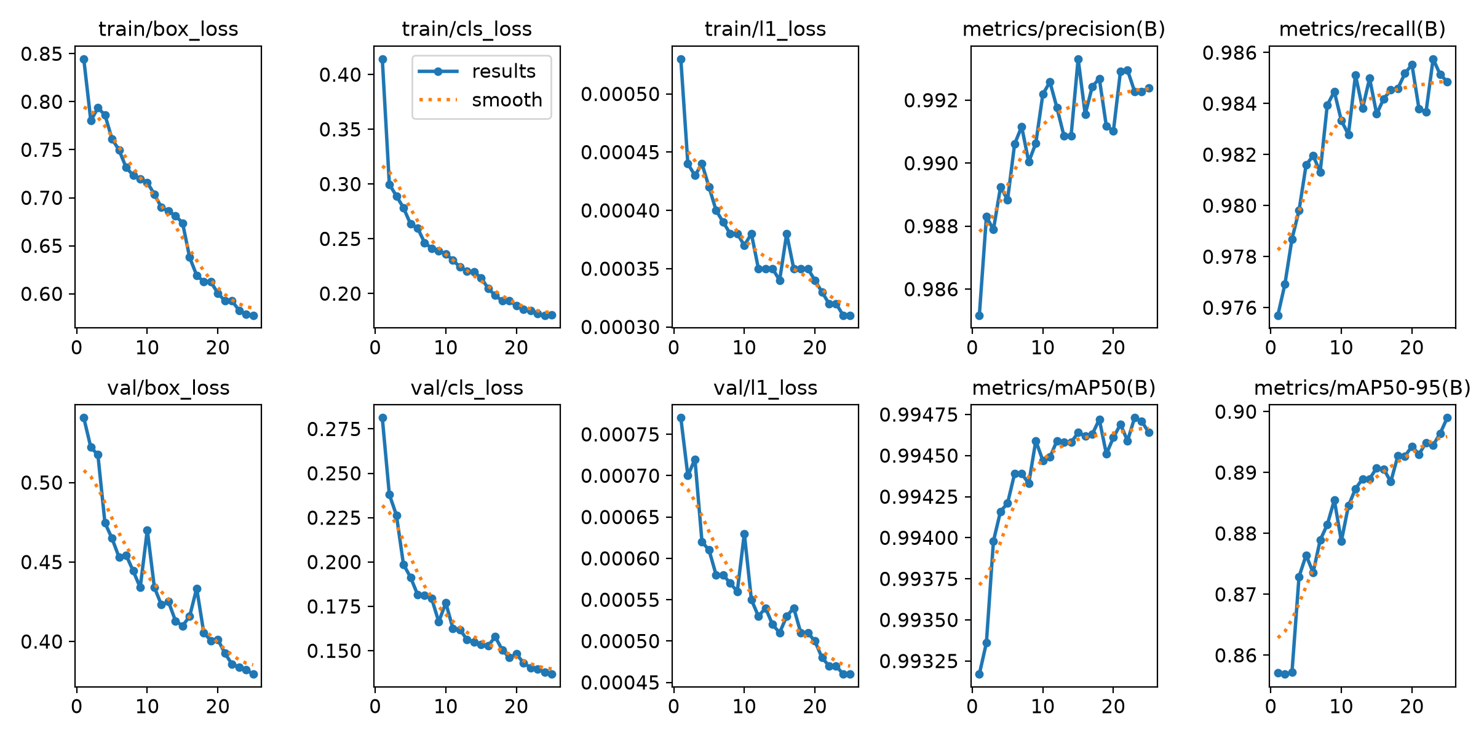
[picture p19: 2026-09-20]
computer-vision/docs/demo/2_training/ultralytics_25_epochs/results.png

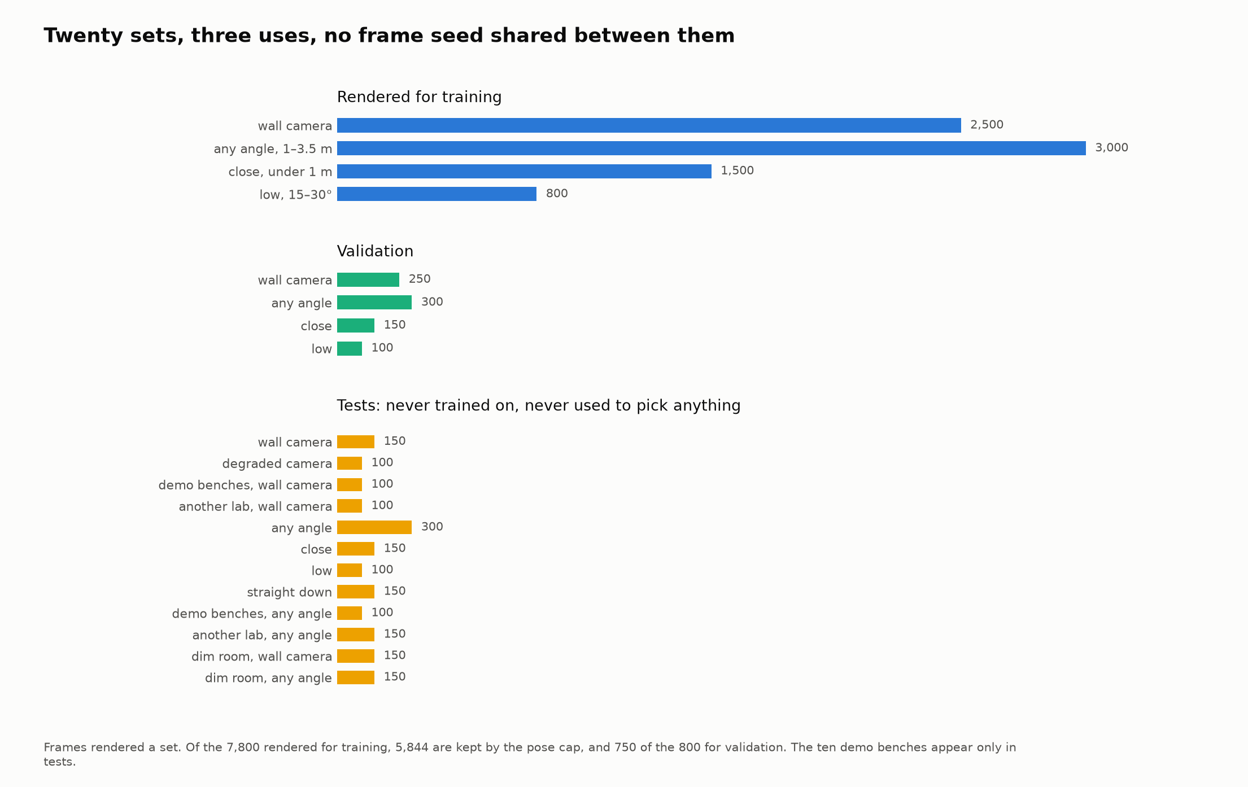
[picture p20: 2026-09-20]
computer-vision/docs/demo/1_dataset/sets_train_validation_test.png

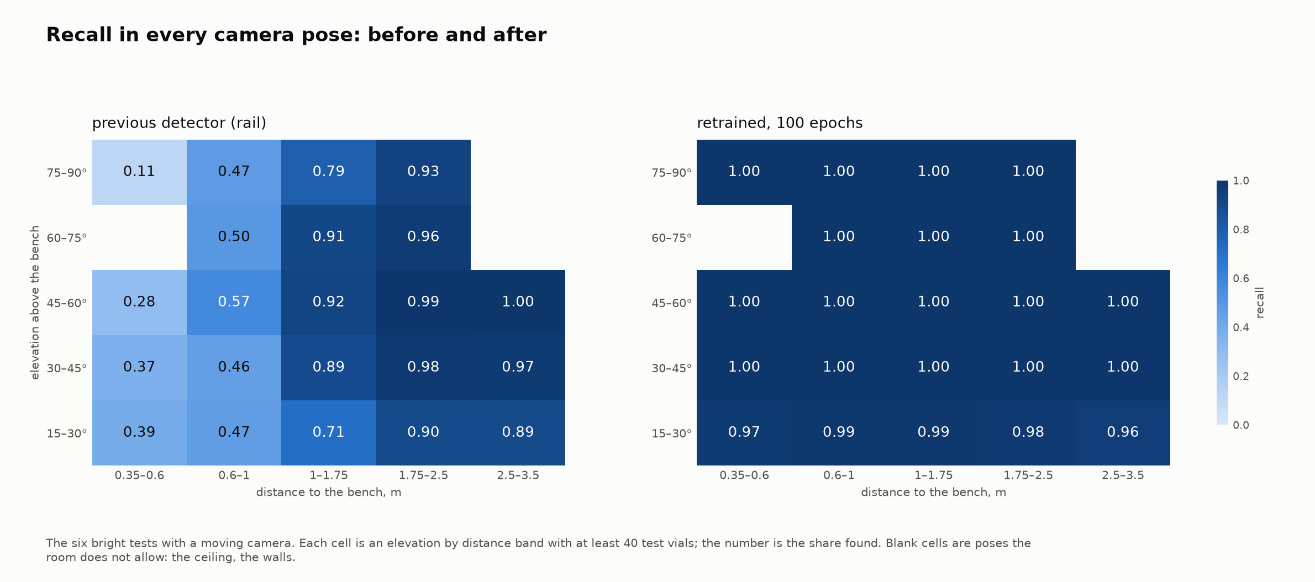
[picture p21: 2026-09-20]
computer-vision/docs/demo/3_results/recall_by_pose_cell_before_and_after.png

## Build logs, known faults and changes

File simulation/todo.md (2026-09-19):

# Simulation — map & TODO (Eloi's lane)

Wayfinder map for the simulation lane, kept as plain markdown (no issue tracker).

## Destination

An integrated demo: a **simulated lab-automation task that emits camera frames**
for the computer-vision team to process. First value = **get images to CV fast**
so they can start; the polished pipeline (Isaac Sim + Replicator on RunPod) follows.

## Notes

- Scope: **Eloi's lane only**. Eki drives the MuJoCo/AutoBio lane separately.
- This map carries **execution**, not just decisions (hackathon: we ship).
- Platform: **NVIDIA Isaac Sim/Lab on RunPod is primary** — a real NVIDIA GPU
  renders Isaac Lab cameras natively, which removes the whole "port cameras to
  Apple/Metal" problem. IsaacLab-mlx on the Mac is optional local dev only.

## Decisions so far

- **Scope = Eloi's lane only.** The MuJoCo/AutoBio lane is Eki's.
- **RunPod (NVIDIA Isaac Sim) is the primary platform**; IsaacLab-mlx demoted to
  optional local dev.
- **Fastest image source = MuJoCo offscreen render on the Mac**, using Eki's
  `minihannover` bench scene (lab-relevant and verified on MuJoCo 3.13) — no
  cloud, no AutoBio Linux plugin. See `scripts/render_dataset.py`.
- **Real labelled dataset = Isaac Sim + Replicator on RunPod**, built in parallel.
- **No interactive Isaac Sim on RunPod.** WebRTC (the official path) needs a UDP
  media port and RunPod blocks UDP; noVNC works over TCP but NVIDIA doesn't
  support the GUI over a virtual display (fragile, RTX-4090/Isaac-4.0 only). So:
  interact in **local MuJoCo**, keep Isaac Sim on RunPod **headless** (render to
  disk); noVNC-over-SSH only as a throwaway. See `runpod-interactive.md`.

## Open

- [ ] **Batch 2 — usable detection data**: objects on the bench (instruments /
      simple primitives) + **segmentation masks** + **depth** from the same
      `render_dataset.py`. Turns bench-only frames into a real CV dataset.
- [ ] **Re-render the arm montage on the de-cluttered open USD (needs an idle GPU).**
      The `minihannover_open` scene now drops the solid/powder jars (working tree:
      `generate_minihannover_open.py` filters stock to `phase == liquid`, 407 → 313
      containers), verified good via `render_usd.py` (bright, de-cluttered bench).
      `arm_pose_render.py` needs re-running to refresh `renders/isaac/arms/` — **no
      code change needed**. Root cause of the "black lab" seen on 2026-09-19 was
      **NOT** our scene change and **NOT** the script: it was **GPU contention** —
      every black arm render happened while a second Isaac RTX process (Eki's
      `dataset_gen*.py`) was running on the same A40; the one render made with the GPU
      idle (`render_usd.py`, 08:45) came out bright. Proof: re-exporting the *old*
      with-solids USD (md5 943931c…, the one that made the committed bright renders)
      and running the unmodified script now *also* renders black while Eki's job runs.
      Diagnostics confirmed geometry+lights+load were all fine at capture, so it's a
      renderer-level conflict between two concurrent Isaac contexts, not the data.
      **Action:** run `ONLY_ARM=franka NPOSES=1` on an **idle** GPU to confirm bright,
      then the full `arm_pose_render.py`, rebuild the montages, done.
      **Coordinate with Eki:** the pod is shared and `dataset_gen*.py` reads
      `/root/lab_usd`; agree on which USD it should hold (de-cluttered =
      md5 467b67ddb776b117d7dd729f7e4df611) before swapping it.

## Not yet specified (fog)

- **CV contract**: resolution / FPS / frame count / label format — pin once the CV
  team reacts to batch 1.
- **Final lab task**: which task, which robot arm, what it manipulates.
- **Replicator dataset**: reuse `minihannover` (URDF→USD) so sim and CV share the
  same bench? Domain-randomisation ranges?
- Whether **AutoBio** frames (Eki, Linux) are needed for extra lab realism.

## Out of scope

- **numi-lab** — Apple-native Metal sim; RunPod renders cameras natively, so no
  longer needed. Reference only.
- **Porting Isaac Lab cameras to MLX/Metal** — mooted by using RunPod.

## Done

- [x] **Isaac Sim on RunPod de-risked** (2026-09-18) — official image
      `nvcr.io/nvidia/isaac-sim:4.5.0` runs headless on an RTX A5000; one 1280×720
      RGB frame rendered to disk via Replicator and pulled back (~$0.15, ~11 min
      end to end). Key unlock: the image's ENTRYPOINT is fixed (streaming app) and
      RunPod's GraphQL/`runpodctl` can't override it, but **REST v2** (`POST
      https://rest.runpod.io/v1/pods`) exposes `dockerEntrypoint` — set it to
      `bash -lc` + an sshd bootstrap and you get a shell. Recipe in
      `runpod-isaac.md`; `scripts/render_isaac.py` + `scripts/runpod_isaac_sshd_boot.sh`.
- [x] **Batch 1 shipped to CV** — 128 RGB frames (640×480) of the `minihannover`
      bench from randomised camera poses + `frames.json`. Generated with
      `scripts/render_dataset.py`; zipped at `out/minihannover_batch1.zip`.
      Bench-only: enough for CV to scaffold their pipeline, not yet a labelled set.

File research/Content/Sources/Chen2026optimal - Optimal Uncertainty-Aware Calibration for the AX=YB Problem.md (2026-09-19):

---
aliases: []
type: "source"
title: "Optimal Uncertainty-Aware Calibration for the AX=YB Problem"
citekey: "Chen2026optimal"
doi: "10.48550/arXiv.2605.04809"
arxiv: "2605.04809"
year: 2026
publication_type: "preprint"
url: "https://arxiv.org/abs/2605.04809"
keywords: []
status: "to-read"
rating: 0
authors: []
authors_unresolved: ["Yanjia Chen", "Xiangfei Li", "Huan Zhao", "Yiyuan Hong", "Guanxiao Xia", "Jiexin Zhang", "Han Ding"]
sha256: ["99109f92f5071cac8dba3b5d21f468c7c61f6581a276f91d13a19aa23238d970"]
pdf: "Content/Papers/Chen2026optimal.pdf"
topics: ["[[Ampliación]]"]
cited_in: ["[[04_huecos_y_ampliacion]]"]
created: "2026-09-18"
created_by: "ingest-writer@25466ccf498f"
checked_by: "ingest-checker@a741699004ec"
ingested: "2026-09-18"
claims: 69
---

📄 PDF: [[Chen2026optimal.pdf]]

> [!abstract] One-sentence summary
> The paper proposes UAL-HED, a Lie-algebra iterative solver for hand-eye and robot-world calibration (AX = YB) that uses a data-driven relative uncertainty metric instead of explicit uncertainty models, and reports lower errors than classical and iterative baselines in simulation and on an industrial robot with a laser tracker.

## Abstract

This article proposes a general optimization framework for solving hand-eye calibration problem. Unlike traditional methods, an iterative algorithm based on Lie algebra that achieves approximately global optimal solutions is developed. During the optimization process, the method strictly preserves the structural constraints of the calibration parameters and enables synchronized updates between calibration parameters. Recognizing that data used in real-word hand-eye calibration often contain uncertainty, especially in over-loading and large workspace industrial robot scenarios, which can significantly degrade accuracy, and accurately modeling such uncertainty is inherently difficult, this article avoids explicit uncertainty modeling. Instead, an uncertainty metric to evaluate the relative uncertainty between data sources is introduced and used to dynamically refine the iterative process. To further enhance convergence efficiency, an effective initial solution generation method that improves overall stability and accuracy is designed. Numerical simulations and real-world experiments validate the effectiveness of the proposed approach, and in synthetic datasets, the proposed approach improves the estimation accuracy by at least 67\% under high-uncertainty conditions compared with the existing methods. (arXiv)

## 🧠 Key ideas (atomic)

- The paper designs its calibration framework for the [[Robot-world and hand-eye calibration (AX = YB)|AX = YB problem]], stating that it is also compatible with the AX = XB problem. (Chen et al., 2026) `ev:asserted` p. 1 ^chen2026optimal-001
- The authors argue that AX = YB can be transformed into [[Hand-eye calibration (AX = XB)|AX = XB]], which makes the [[Robot-world and hand-eye calibration (AX = YB)|AX = YB formulation]] more general. (Chen et al., 2026) `ev:asserted` p. 1 ^chen2026optimal-002
- The study is conducted with the vision measurement system fixed externally in the robot environment, which the authors call readily extendable to robot-mounted sensors. (Chen et al., 2026) `ev:reported` p. 1 ^chen2026optimal-003
- The paper calls system-level or structural uncertainty arising from limited robot precision in hand-eye calibration epistemic uncertainty (EU). (Chen et al., 2026) `ev:asserted` p. 2 ^chen2026optimal-004
- The authors state that epistemic uncertainty sources exhibit dependent rather than independently stochastic behaviour, being systematically mapped from the robot pose. (Chen et al., 2026) `ev:asserted` p. 2 ^chen2026optimal-005
- Robot pose accuracy is often significantly lower than pose repeatability, with resulting errors reaching the millimeter scale in large workspaces or heavy payloads. (Chen et al., 2026) `ev:cited` p. 2 ^chen2026optimal-006
- The authors argue that both epistemic and aleatoric uncertainty ultimately manifest in calibration only through distortions in the source data {Ai} and {Bi}. (Chen et al., 2026) `ev:asserted` p. 2 ^chen2026optimal-007
- The authors state that decoupled methods for solving X and Y are prone to cumulative and propagated errors, unlike synchronous solving. (Chen et al., 2026) `ev:asserted` p. 4 ^chen2026optimal-008
- [[Hand-eye calibration (AX = XB)|Linear hand-eye calibration methods]] minimize algebraic errors, so their achievable accuracy is inherently bounded and sensitive to the uncertainty in the data. (Chen et al., 2026) `ev:cited` p. 4 ^chen2026optimal-009
- The paper notes that there is no bi-invariant distance on SE(3), so solution accuracy may depend on the chosen minimization model. (Chen et al., 2026) `ev:asserted` p. 6 ^chen2026optimal-010
- The authors state that iterating rotation and translation, or X and Y, separately propagates computational errors, making synchronized iteration the optimal method. (Chen et al., 2026) `ev:asserted` p. 6 ^chen2026optimal-011
- Data pair correspondence is checked by requiring the screw rotation angles and pitches of the relative motions Aij and Bij to match within thresholds. (Chen et al., 2026) `ev:reported` p. 6 ^chen2026optimal-012
- The L-HED objective uses a Mahalanobis distance on linearized Lie-algebra residuals to handle the differing physical units of rotation and translation. (Chen et al., 2026) `ev:reported` p. 7 ^chen2026optimal-013
- L-HED updates the Lie-algebra increments of X and Y jointly with a momentum gradient scheme meant to accelerate convergence and reduce oscillations. (Chen et al., 2026) `ev:reported` p. 7 ^chen2026optimal-014
- Small stochastic perturbations are added to the gradient when necessary, to escape local optima and facilitate computing a globally optimal solution. (Chen et al., 2026) `ev:reported` p. 7 ^chen2026optimal-015
- A Lie algebra-based residual metric serves as the heuristic indicator for selecting stochastic perturbations, since unselected perturbations would disrupt convergence properties. (Chen et al., 2026) `ev:reported` p. 8 ^chen2026optimal-016
- The paper states that convexity of its objective requires an affine deviation in the increments and a positive definite weighting covariance matrix. (Chen et al., 2026) `ev:asserted` p. 8 ^chen2026optimal-017
- The authors avoid explicit modeling of the source-data error term, arguing that imprecise uncertainty modeling can degrade the solution accuracy. (Chen et al., 2026) `ev:asserted` p. 9 ^chen2026optimal-018
- Each source dataset is decentralized with its iteratively computed SE(3) mean and covariance, yielding normalized vectors for every data pair. (Chen et al., 2026) `ev:reported` p. 9 ^chen2026optimal-019
- The derivation shows that without uncertainty the norms of the normalized vectors from {Ai} and {Bi} must be equal for each corresponding pair. (Chen et al., 2026) `ev:computed` p. 9 ^chen2026optimal-020
- The inequality between the normalized-vector norms is used as a metric quantifying relative uncertainty between the source datasets {Ai} and {Bi}. (Chen et al., 2026) `ev:asserted` p. 9 ^chen2026optimal-021
- The uncertainty correction combines per-pair norm ratios with covariance ratios, weighted by an influence factor computed from dataset variances. (Chen et al., 2026) `ev:reported` p. 10 ^chen2026optimal-022
- The paper names its relative uncertainty metric the Sharpe Ratio Metric under the Euclidean group, abbreviated SRM@SE(3). (Chen et al., 2026) `ev:asserted` p. 3 ^chen2026optimal-023
- Incorporating SRM@SE(3) into L-HED produces the UAL-HED method, which the authors present for optimization with highly uncertain data sources. (Chen et al., 2026) `ev:asserted` p. 3 ^chen2026optimal-024
- The SI-AH initial solver obtains the rotation of X by singular value decomposition over screw-axis vectors of the relative motions. (Chen et al., 2026) `ev:reported` p. 11 ^chen2026optimal-025
- SI-AH then refines the rotation and translation of X jointly with a Levenberg-Marquardt iteration to eliminate errors from separate solving. (Chen et al., 2026) `ev:reported` p. 11 ^chen2026optimal-026
- In simulation, robot poses are assumed error-free while synthesized camera observations carry robot aleatoric errors, robot epistemic errors and measurement errors. (Chen et al., 2026) `ev:reported` p. 11 ^chen2026optimal-027
- In simulation, the uncertainty metric increased approximately proportionally as the magnitude of injected uncertainty increased across Error Scenarios 1 to 10. (Chen et al., 2026) `ev:measured` p. 12 ^chen2026optimal-028
- High rotational aleatoric uncertainty had a greater impact on the uncertainty metric than high translational aleatoric uncertainty in Error Scenarios 11 to 18. (Chen et al., 2026) `ev:measured` p. 12 ^chen2026optimal-029
- From different initial values, the heuristic error metric of L-HED converged to the same level of accuracy in the simulation study. (Chen et al., 2026) `ev:measured` p. 12 ^chen2026optimal-030
- With an initial value close to the optimal matrices, L-HED reached the designed stopping threshold in 7,734 iterations. (Chen et al., 2026) `ev:measured` p. 12 ^chen2026optimal-031
- With initial values far from the optimal matrices, L-HED convergence was achieved after 30,731 iterations in the simulation. (Chen et al., 2026) `ev:measured` p. 12 ^chen2026optimal-032
- Using the identity matrix as initial value, L-HED still converged, but the number of iterations increased significantly to 128518. (Chen et al., 2026) `ev:measured` p. 12 ^chen2026optimal-033
- Seven methods were compared: L-HED, UAL-HED, SI-AH, dual quaternions, Kronecker product, LMI-SDP optimization and decoupled point cloud matching. (Chen et al., 2026) `ev:reported` p. 13 ^chen2026optimal-034
- Compared to L-HED, UAL-HED reduced the average estimation error of X by 7.1% across six synthetic uncertainty combinations. (Chen et al., 2026) `ev:measured` p. 13 ^chen2026optimal-035
- Compared to L-HED, UAL-HED achieved a 10.6% reduction in the average estimation error of Y on synthesized data. (Chen et al., 2026) `ev:measured` p. 13 ^chen2026optimal-036
- Compared to the LMI method, UAL-HED reduced the average estimation error of X by 81.1% on synthesized data. (Chen et al., 2026) `ev:measured` p. 13 ^chen2026optimal-037
- Compared to the LMI method, UAL-HED achieved a 79.5% reduction in the average estimation error of Y on synthesized data. (Chen et al., 2026) `ev:measured` p. 13 ^chen2026optimal-038
- The decoupled point cloud matching method performed worst, with UAL-HED achieving a 91.7% lower estimation error for X. (Chen et al., 2026) `ev:measured` p. 13 ^chen2026optimal-039
- For Y, UAL-HED reduced the estimation error by 90.6% compared to the point cloud matching method in simulation. (Chen et al., 2026) `ev:measured` p. 13 ^chen2026optimal-040
- Under simple uncertainty combinations, the SI-AH initial solver also performed strongly, even achieving the best result in the first scenario. (Chen et al., 2026) `ev:measured` p. 13 ^chen2026optimal-041
- The authors attribute this to the L-HED heuristic metric not being constructed from the true ideal matrices, risking overfitting near the optimum. (Chen et al., 2026) `ev:asserted` p. 13 ^chen2026optimal-042
- Across the six scenarios, UAL-HED achieved on average a 74.7% lower estimation error than SI-AH for X. (Chen et al., 2026) `ev:measured` p. 14 ^chen2026optimal-043
- Across the six scenarios, UAL-HED achieved on average a 73.5% lower estimation error than SI-AH for Y. (Chen et al., 2026) `ev:measured` p. 14 ^chen2026optimal-044
- For individual synthesized datasets another method may be most accurate, but UAL-HED most frequently attained the highest accuracy in simulation. (Chen et al., 2026) `ev:measured` p. 14 ^chen2026optimal-045
- Under high uncertainty in both source datasets, all seven methods estimated X noticeably less accurately than under low uncertainty. (Chen et al., 2026) `ev:measured` p. 15 ^chen2026optimal-046
- The two decoupled methods showed the greatest decrease in accuracy under high uncertainty, which the authors take to indicate error propagation and accumulation. (Chen et al., 2026) `ev:measured` p. 15 ^chen2026optimal-047
- In these simulations, rotational uncertainty had a greater tendency to disrupt the estimation of calibration parameters than positional uncertainty. (Chen et al., 2026) `ev:measured` p. 15 ^chen2026optimal-048
- L-HED, UAL-HED and SI-AH estimated X with the same accuracy whether only {Ai} or only {Bi} had high uncertainty. (Chen et al., 2026) `ev:measured` p. 15 ^chen2026optimal-049
- As source-data uncertainty increased, the relative effectiveness of UAL-HED compared to L-HED gradually improved in the simulations. (Chen et al., 2026) `ev:measured` p. 15 ^chen2026optimal-050
- Under the simulated conditions, UAL-HED exhibited the smallest variance in the estimation error of X, followed by L-HED. (Chen et al., 2026) `ev:measured` p. 15 ^chen2026optimal-051
- Estimation errors for Y were higher than those for X across all seven methods in the 16-setting simulation study. (Chen et al., 2026) `ev:measured` p. 16 ^chen2026optimal-052
- Four [[Robot-world and hand-eye calibration (AX = YB)|closed-form constructions of AX = YB]] used within L-HED from the same initial value showed different iterative convergence behaviour. (Chen et al., 2026) `ev:measured` p. 16 ^chen2026optimal-053
- After swapping the translational components of X and Y, the ranking of closed-form constructions reversed, which the authors take to confirm their hypothesis. (Chen et al., 2026) `ev:measured` p. 17 ^chen2026optimal-054
- Increasing the number of source data sets improved accuracy for all seven methods, with accuracy tending to stabilize once 100 sets were reached. (Chen et al., 2026) `ev:measured` p. 17 ^chen2026optimal-055
- Under high uncertainty, selecting source data with lower uncertainty metrics gave higher accuracy for four baseline methods than no data selection. (Chen et al., 2026) `ev:measured` p. 18 ^chen2026optimal-056
- Among five residual forms, the homogeneous-transformation-matrix residual most accurately reflected the ground-truth ranking of calibration estimation errors in simulation. (Chen et al., 2026) `ev:measured` p. 18 ^chen2026optimal-057
- Real-world experiments used an ABB IRB 6700 155/2.85 robot with a laser tracker and T-Mac providing 6-DoF measurements. (Chen et al., 2026) `ev:reported` p. 18 ^chen2026optimal-058
- The robot carried an end-effector with a gravity-compensated calculated weight of 47 kg during the real-world calibration experiments. (Chen et al., 2026) `ev:reported` p. 18 ^chen2026optimal-059
- In each of two workspace configurations, 100 source data pairs were collected for estimation, followed by 99 additional pairs for validation. (Chen et al., 2026) `ev:reported` p. 19 ^chen2026optimal-060
- The average uncertainty metric in the large workspace was 1.56 times that of the small workspace in the real-world experiments. (Chen et al., 2026) `ev:measured` p. 19 ^chen2026optimal-061
- According to the authors, UAL-HED achieved the best HTM-based residual in both the high-uncertainty and low-uncertainty real-world workspaces. (Chen et al., 2026) `ev:measured` p. 19 ^chen2026optimal-062
- With UAL-HED in the high-uncertainty workspace, the average position difference between transformed camera data and teach pendant data was 0.293 mm. (Chen et al., 2026) `ev:measured` p. 20 ^chen2026optimal-063
- With UAL-HED in the low-uncertainty workspace, the average position difference between transformed camera data and teach pendant data was 0.158 mm. (Chen et al., 2026) `ev:measured` p. 20 ^chen2026optimal-064
- On validation pairs in the high-uncertainty workspace, UAL-HED had a conversion error of 0.342mm, versus 0.346mm for L-HED. (Chen et al., 2026) `ev:measured` p. 21 ^chen2026optimal-065
- In the high-uncertainty workspace, the baseline conversion errors ranged from 0.671mm for Dual-Quaternion to 1.17mm for Kronecker-Product. (Chen et al., 2026) `ev:measured` p. 21 ^chen2026optimal-066
- In the low-uncertainty workspace, L-HED had a conversion error of 0.193mm, lower than the 0.202mm of UAL-HED. (Chen et al., 2026) `ev:measured` p. 21 ^chen2026optimal-067
- In the abstract, the approach is said to improve estimation accuracy by at least 67% under high uncertainty on synthetic datasets. (Chen et al., 2026) `ev:abstract` p. 1 ^chen2026optimal-068
- The authors conclude that source-data uncertainty significantly impacts calibration accuracy, particularly with a large uncertainty disparity between {Ai} and {Bi}. (Chen et al., 2026) `ev:asserted` p. 21 ^chen2026optimal-069

## 🎯 Contributions

## 📖 Glossary

- **AX = YB** — Hand-eye plus robot-world calibration equation with two unknown rigid transforms X and Y.
- **AX = XB** — Classical hand-eye calibration equation with one unknown transform from relative motions.
- **HECPs** — Hand-eye calibration parameters, the unknown transforms X and Y.
- **Aleatoric uncertainty (AU)** — Random, typically Gaussian-modelled measurement noise in calibration source data.
- **Epistemic uncertainty (EU)** — Pose-dependent, structural error from limited robot pose accuracy.
- **L-HED** — Lie algebra-based heuristic escape descent: synchronized X, Y iteration with stochastic local-minimum escape.
- **UAL-HED** — L-HED corrected by the SRM@SE(3) relative uncertainty metric.
- **SRM@SE(3)** — Sharpe Ratio Metric on SE(3), a relative uncertainty measure between two source datasets.
- **SI-AH** — Scale-invariant analytical heuristic method providing initial X, Y estimates via screw invariants.
- **Robot pose accuracy (RPA)** — Ability of a robot to reach a commanded pose in space.
- **Robot pose repeatability (RPR)** — Ability of a robot to return consistently to the same pose.
- **Bi-invariant metric** — A distance invariant under both left and right group multiplication; SE(3) lacks one.

## ❓ Open questions

- Why does UAL-HED not beat L-HED in the low-uncertainty real-world workspace conversion error (Table 9), despite the text claiming it is consistently best?
- How sensitive are L-HED iteration counts and final accuracy to the stochastic perturbation magnitude and escape criterion?
- Can the closed-form construction be chosen automatically from the data, since the best form depends on the relative translation magnitudes of X and Y?
- Does the SRM@SE(3) metric remain informative for camera-based (not laser-tracker) sensing with larger aleatoric noise?
- Where does the abstract's figure of at least 67% improvement come from, given that the body reports different percentages?
- How does runtime scale, given convergence can require over a hundred thousand iterations from a poor initial value?

## 📝 Notes on reading

Version read: arXiv preprint 2605.04809v1, typeset with a SAGE journal template (placeholder journal title and DOI).

The abstract's "at least 67%" improvement figure is not found in the body text; Section 5.1.4 reports 7.1%/10.6% versus L-HED, 81.1%/79.5% versus LMI, 91.7%/90.6% versus point cloud matching and 74.7%/73.5% versus SI-AH.

Inconsistency: Section 5.1.4 (p. 13) says dual quaternions are better for X and the Kronecker product for Y, whereas Section 5.1.5 (p. 16) says dual quaternions are more accurate for Y, the opposite of the trend for X. The Y comparison was therefore not claimed.

Inconsistency: p. 19 says UAL-HED consistently achieves the best performance in both workspaces, but Table 9 (p. 21) lists L-HED at 0.193mm and UAL-HED at 0.202mm in the low-uncertainty workspace.

Inconsistency: p. 15 refers to "two decoupled methods", but p. 13 identifies only point cloud matching as decoupled.

Table 3 (p. 14) is garbled in extraction: the translational columns of the PCM and SI-AH rows are shifted or duplicated, and the translational Y columns show near-identical values across all methods; per-cell values were not claimed. Table 1 and Table 2 column alignment is also partly lost.

Figures 5-26 (uncertainty metric trends, convergence curves, error bars, workspace sketches, 6-DoF difference plots) could only be described from their captions and surrounding text. Figure 1 (framework) and Figure 3 extracted as scattered symbols.

Several cross-references read "Section" with no number (Algorithm 1 inputs, p. 9), and p. 9 cites Equation (42) where the uncertainty correction appears to be Equation (43). The laser tracker is spelled "Lecia AT 960" in the text.

## Suggested new concepts

- Hand-eye and robot-world calibration (AX = YB) — central formulation shared by camera-robot registration papers.
- Epistemic vs aleatoric uncertainty in robot calibration — distinguishes pose-dependent robot error from sensor noise.
- Lie-group optimization on SE(3) — common machinery for pose estimation and calibration solvers.
- Robot pose accuracy vs repeatability — key constraint for non-teaching, vision-guided industrial tasks.
- Calibration data selection — choosing informative, low-uncertainty pose pairs improves calibration accuracy.

## Por qué es relevante

- **[[04_huecos_y_ampliacion]]** — **H5.** Iteración en el álgebra de Lie para AX=YB que repondera según la incertidumbre relativa entre cinemática y visión.

<!-- ingest-checker dropped 1 claim(s); see _harness/log/ingest.jsonl (claim-dropped) -->

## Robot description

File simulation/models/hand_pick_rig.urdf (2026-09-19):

<?xml version="1.0" encoding="utf-8"?>
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
<robot name="hand_pick_rig">
  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
  <mujoco>
    <compiler discardvisual="false" fusestatic="false"/>
  </mujoco>

  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

  <link name="rig_base">
    <inertial>
      <origin xyz="0 0 0" rpy="0 0 0"/>
      <mass value="0.001"/>
      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
    </inertial>
  </link>
  <link name="reach_link">
    <inertial>
      <origin xyz="0 0 0" rpy="0 0 0"/>
      <mass value="1"/>
      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
    </inertial>
  </link>
  <link name="lift_link">
    <inertial>
      <origin xyz="0 0 0" rpy="0 0 0"/>
      <mass value="1"/>
      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
    </inertial>
  </link>
  <link name="ur10e_hand">
    <inertial>
      <origin xyz="0 0 -0.099" rpy="0 0 0"/>
      <mass value="1"/>
      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
    </inertial>
    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
  </link>
  <link name="wrist_3_link">
    <inertial>
      <origin xyz="0 0 -0.008" rpy="-1.5708 1.5708 0"/>
      <mass value="0.202"/>
      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
    </inertial>
    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
  </link>
  <link name="base_mount">
    <inertial>
      <origin xyz="-0.000360584 8.53627e-05 -5.91991e-05" rpy="0.00147918 -1.56795 -3.14159"/>
      <mass value="0.150003"/>
      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
    </inertial>
    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
  </link>
  <link name="base">
    <inertial>
      <origin xyz="0 -2.70394e-05 0.0354675" rpy="-0.00305698 0 0"/>
      <mass value="0.777441"/>
      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
    </inertial>
    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
  </link>
  <link name="right_driver">
    <inertial>
      <origin xyz="2.96931e-12 0.0177547 0.00107314" rpy="1.64252 0 0"/>
      <mass value="0.00899563"/>
      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
    </inertial>
    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
  </link>
  <link name="right_coupler">
    <inertial>
      <origin xyz="0 0.00301209 0.0232175" rpy="0 0.129039 1.5708"/>
      <mass value="0.0140974"/>
      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
    </inertial>
    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
  </link>
  <link name="right_spring_link">
    <inertial>
      <origin xyz="-8.65005e-09 0.0181624 0.0212658" rpy="0 0.706844 1.5708"/>
      <mass value="0.0221642"/>
      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
    </inertial>
    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
  </link>
  <link name="right_follower">
    <inertial>
      <origin xyz="0 0.006954 0.0059786" rpy="0.329778 0 0"/>
      <mass value="0.0125222"/>
      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
    </inertial>
    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
  </link>
  <link name="right_pad">
    <inertial>
      <origin xyz="0 -0.0025 0.0185" rpy="0 0 1.5708"/>
      <mass value="0.0035"/>
      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
    </inertial>
    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
  </link>
  <link name="right_silicone_pad">
    <inertial>
      <origin xyz="-4.7619e-19 -0.0058 0.0185174" rpy="0 0 1.5708"/>
      <mass value="0.00130281"/>
      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
    </inertial>
    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
  </link>
  <link name="left_driver">
    <inertial>
      <origin xyz="0 0.0177547 0.00107314" rpy="1.64252 0 0"/>
      <mass value="0.00899563"/>
      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
    </inertial>
    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
  </link>
  <link name="left_coupler">
    <inertial>
      <origin xyz="0 0.00301209 0.0232175" rpy="0 0.129039 1.5708"/>
      <mass value="0.0140974"/>
      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
    </inertial>
    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
  </link>
  <link name="left_spring_link">
    <inertial>
      <origin xyz="-8.65005e-09 0.0181624 0.0212658" rpy="0 0.706844 1.5708"/>
      <mass value="0.0221642"/>
      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
    </inertial>
    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
  </link>
  <link name="left_follower">
    <inertial>
      <origin xyz="0 0.006954 0.0059786" rpy="0.329778 0 0"/>
      <mass value="0.0125222"/>
      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
    </inertial>
    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
  </link>
  <link name="left_pad">
    <inertial>
      <origin xyz="0 -0.0025 0.0185" rpy="0 0 1.5708"/>
      <mass value="0.0035"/>
      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
    </inertial>
    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
  </link>
  <link name="left_silicone_pad">
    <inertial>
      <origin xyz="-4.7619e-19 -0.0058 0.0185174" rpy="0 0 1.5708"/>
      <mass value="0.00130281"/>
      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
    </inertial>
    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
  </link>

  <joint name="reach" type="prismatic">
    <parent link="rig_base"/>
    <child link="reach_link"/>
    <origin xyz="0 0 0" rpy="0 0 0"/>
    <axis xyz="1 0 0"/>
    <limit lower="-0.5" upper="0.5" effort="200" velocity="0.5"/>
  </joint>
  <joint name="lift" type="prismatic">
    <parent link="reach_link"/>
    <child link="lift_link"/>
    <origin xyz="0 0 0" rpy="0 0 0"/>
    <axis xyz="0 0 1"/>
    <limit lower="0" upper="0.6" effort="200" velocity="0.5"/>
  </joint>
  <joint name="hand_mount" type="fixed">
    <parent link="lift_link"/>
    <child link="ur10e_hand"/>
    <origin xyz="0 0 0" rpy="1.74533 0 1.5708"/>
  </joint>
  <joint name="wrist_3_joint" type="revolute">
    <parent link="ur10e_hand"/>
    <child link="wrist_3_link"/>
    <origin xyz="0 0 0" rpy="0 0 0"/>
    <axis xyz="0 0 1"/>
    <limit lower="-6.28319" upper="6.28319" effort="56" velocity="3.14"/>
  </joint>
  <joint name="base_mount_mount" type="fixed">
    <parent link="wrist_3_link"/>
    <child link="base_mount"/>
    <origin xyz="0 0 0.007" rpy="0 0 0"/>
  </joint>
  <joint name="base_mount" type="fixed">
    <parent link="base_mount"/>
    <child link="base"/>
    <origin xyz="0 0 0.0038" rpy="0 0 -1.5708"/>
  </joint>
  <joint name="right_driver_joint" type="revolute">
    <parent link="base"/>
    <child link="right_driver"/>
    <origin xyz="0 0.0306011 0.054904" rpy="0 0 0"/>
    <axis xyz="1 0 0"/>
    <limit lower="0" upper="0.8" effort="5" velocity="2"/>
  </joint>
  <joint name="right_coupler_joint" type="fixed">
    <parent link="right_driver"/>
    <child link="right_coupler"/>
    <origin xyz="0 0.0315 -0.0041" rpy="0 0 0"/>
  </joint>
  <joint name="right_spring_link_joint" type="revolute">
    <parent link="base"/>
    <child link="right_spring_link"/>
    <origin xyz="0 0.0132 0.0609" rpy="0 0 0"/>
    <axis xyz="1 0 0"/>
    <limit lower="-0.296706" upper="0.8" effort="5" velocity="2"/>
    <mimic joint="right_driver_joint" multiplier="1" offset="0"/>
  </joint>
  <joint name="right_follower_joint" type="revolute">
    <parent link="right_spring_link"/>
    <child link="right_follower"/>
    <origin xyz="0 0.037 0.044" rpy="0 0 0"/>
    <axis xyz="1 0 0"/>
    <limit lower="-0.872664" upper="0.872664" effort="5" velocity="2"/>
    <mimic joint="right_driver_joint" multiplier="-0.9615" offset="0"/>
  </joint>
  <joint name="right_pad_mount" type="fixed">
    <parent link="right_follower"/>
    <child link="right_pad"/>
    <origin xyz="0 -0.0009 0.00702" rpy="0 0 0"/>
  </joint>
  <joint name="right_silicone_pad_mount" type="fixed">
    <parent link="right_pad"/>
    <child link="right_silicone_pad"/>
    <origin xyz="0 0 0" rpy="0 0 0"/>
  </joint>
  <joint name="left_driver_joint" type="revolute">
    <parent link="base"/>
    <child link="left_driver"/>
    <origin xyz="0 -0.0306011 0.054904" rpy="0 0 3.14159"/>
    <axis xyz="1 0 0"/>
    <limit lower="0" upper="0.8" effort="5" velocity="2"/>
    <mimic joint="right_driver_joint" multiplier="1" offset="0"/>
  </joint>
  <joint name="left_coupler_joint" type="fixed">
    <parent link="left_driver"/>
    <child link="left_coupler"/>
    <origin xyz="0 0.0315 -0.0041" rpy="0 0 0"/>
  </joint>
  <joint name="left_spring_link_joint" type="revolute">
    <parent link="base"/>
    <child link="left_spring_link"/>
    <origin xyz="0 -0.0132 0.0609" rpy="0 0 3.14159"/>
    <axis xyz="1 0 0"/>
    <limit lower="-0.296706" upper="0.8" effort="5" velocity="2"/>
    <mimic joint="right_driver_joint" multiplier="1" offset="0"/>
  </joint>
  <joint name="left_follower_joint" type="revolute">
    <parent link="left_spring_link"/>
    <child link="left_follower"/>
    <origin xyz="0 0.037 0.044" rpy="0 0 0"/>
    <axis xyz="1 0 0"/>
    <limit lower="-0.872664" upper="0.872664" effort="5" velocity="2"/>
    <mimic joint="right_driver_joint" multiplier="-0.9615" offset="0"/>
  </joint>
  <joint name="left_pad_mount" type="fixed">
    <parent link="left_follower"/>
    <child link="left_pad"/>
    <origin xyz="0 -0.0009 0.00702" rpy="0 0 0"/>
  </joint>
  <joint name="left_silicone_pad_mount" type="fixed">
    <parent link="left_pad"/>
    <child link="left_silicone_pad"/>
    <origin xyz="0 0 0" rpy="0 0 0"/>
  </joint>
</robot>

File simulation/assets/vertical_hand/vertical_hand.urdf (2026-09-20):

<?xml version="1.0"?>
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
<robot name="vertical_hand">
  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
  <link name="vertical_hand"/>
  <link name="approach">
    <inertial><origin xyz="0 0 0"/><mass value="0.5"/>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</inertial>
  </link>
  <link name="hand">
    <inertial><origin xyz="0 0 0"/><mass value="3"/>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</inertial>
    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
  </link>
  <link name="jaw_l">
    <inertial><origin xyz="0 0 0"/><mass value="0.12"/>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</inertial>
    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
  </link>
  <link name="jaw_r">
    <inertial><origin xyz="0 0 0"/><mass value="0.12"/>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</inertial>
    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
  </link>
  <link name="clamp_slide">
    <inertial><origin xyz="0 0 0"/><mass value="0.3"/>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</inertial>
    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
  </link>
  <link name="clamp_lift">
    <inertial><origin xyz="0 0 0"/><mass value="0.35"/>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</inertial>
    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
  </link>
  <link name="housing">
    <inertial><origin xyz="0 0 0"/><mass value="0.3"/>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</inertial>
    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
  </link>
  <link name="cam">
    <inertial><origin xyz="0 0 0"/><mass value="0.05"/>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</inertial>
    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
  </link>
  <link name="sun">
    <inertial><origin xyz="0 0 0"/><mass value="0.01"/>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</inertial>
    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
  </link>
  <link name="planet_0">
    <inertial><origin xyz="0 0 0"/><mass value="0.01"/>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</inertial>
    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
  </link>
  <link name="planet_1">
    <inertial><origin xyz="0 0 0"/><mass value="0.01"/>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</inertial>
    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
  </link>
  <link name="planet_2">
    <inertial><origin xyz="0 0 0"/><mass value="0.01"/>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</inertial>
    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
  </link>
  <link name="blade_0">
    <inertial><origin xyz="0 0 0"/><mass value="0.005"/>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</inertial>
    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
  </link>
  <link name="blade_1">
    <inertial><origin xyz="0 0 0"/><mass value="0.005"/>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</inertial>
    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
  </link>
  <link name="blade_2">
    <inertial><origin xyz="0 0 0"/><mass value="0.005"/>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</inertial>
    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
  </link>
  <link name="blade_3">
    <inertial><origin xyz="0 0 0"/><mass value="0.005"/>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</inertial>
    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
  </link>
  <link name="blade_4">
    <inertial><origin xyz="0 0 0"/><mass value="0.005"/>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</inertial>
    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
  </link>
  <link name="blade_5">
    <inertial><origin xyz="0 0 0"/><mass value="0.005"/>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</inertial>
    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
  </link>
  <link name="pip_slide">
    <inertial><origin xyz="0 0 0"/><mass value="0.4"/>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</inertial>
    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
  </link>
  <link name="plunger">
    <inertial><origin xyz="0 0 0"/><mass value="0.01"/>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</inertial>
    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
  </link>
  <joint name="approach" type="prismatic">
    <parent link="vertical_hand"/><child link="approach"/>
    <origin xyz="0 0 0" rpy="0 0 0"/>
    <axis xyz="1 0 0"/>
    <limit lower="-0.2" upper="0.05" effort="200" velocity="2.0"/>
  </joint>
  <joint name="lift" type="prismatic">
    <parent link="approach"/><child link="hand"/>
    <origin xyz="0 0 0" rpy="0 0 0"/>
    <axis xyz="0 0 1"/>
    <limit lower="0" upper="0.3" effort="600" velocity="2.0"/>
  </joint>
  <joint name="jaw_l" type="prismatic">
    <parent link="hand"/><child link="jaw_l"/>
    <origin xyz="0 0 0.0571" rpy="0 0 0"/>
    <axis xyz="0 1 0"/>
    <limit lower="0.0117763" upper="0.0613506" effort="60" velocity="2.0"/>
  </joint>
  <joint name="jaw_r" type="prismatic">
    <parent link="hand"/><child link="jaw_r"/>
    <origin xyz="0 0 0.0571" rpy="0 0 0"/>
    <axis xyz="0 -1 0"/>
    <limit lower="0.0117763" upper="0.0613506" effort="20" velocity="2.0"/>
    <mimic joint="jaw_l" multiplier="1" offset="0"/>
  </joint>
  <joint name="clamp_x" type="prismatic">
    <parent link="hand"/><child link="clamp_slide"/>
    <origin xyz="0 0 0" rpy="0 0 0"/>
    <axis xyz="1 0 0"/>
    <limit lower="-0.1" upper="0" effort="200" velocity="2.0"/>
  </joint>
  <joint name="clamp_lift" type="prismatic">
    <parent link="clamp_slide"/><child link="clamp_lift"/>
    <origin xyz="0 0 0.0796" rpy="0 0 0"/>
    <axis xyz="0 0 1"/>
    <limit lower="0" upper="0.0355" effort="200" velocity="2.0"/>
  </joint>
  <joint name="body_yaw" type="revolute">
    <parent link="clamp_lift"/><child link="housing"/>
    <origin xyz="0 0 0" rpy="0 0 0"/>
    <axis xyz="0 0 1"/>
    <limit lower="0" upper="15.708" effort="20" velocity="10.0"/>
  </joint>
  <joint name="cam" type="revolute">
    <parent link="housing"/><child link="cam"/>
    <origin xyz="0 0 0" rpy="0 0 0"/>
    <axis xyz="0 0 -1"/>
    <limit lower="0" upper="1.39626" effort="10" velocity="10.0"/>
  </joint>
  <joint name="sun" type="revolute">
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

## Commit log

2026-09-18 Add the minihannover lab bench asset
    A 6.0 x 1.5 m bench with the work surface at 0.90 m, usable from both
    simulators. scripts/generate_minihannover.py is the single source of truth:
    it emits the OBJ interchange mesh, two MJCF variants and the URDF that the
    Isaac Lab importer reads, so the descriptions cannot drift apart.
    Shared frame convention: origin on the floor, centred in X/Y, +X along the
    length. Collision is seven boxes (worktop plus three leg pairs; a 6 m top
    needs the mid support) rather than the mesh, because the convex hull of a
    table is a solid block. The body carries no joint, so it is welded to the
    world.
    Verified in MuJoCo 3.13.0: all three model files load, the collision A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
    [minihannover.obj, minihannover.urdf]
2026-09-18 Document which assets each simulator can consume
    Inventory of the 3D assets with a per-format support matrix for MuJoCo and
    Isaac Lab, plus the traps found while checking the two instrument folders
    against MuJoCo 3.13.0:
    - MuJoCo imports only the first `g` group of a multi-group OBJ, and does so
    without an error. gc-ms keeps 204 of its 185754 faces, uv-vs-nr 5180 of
    5761. Stripping the `g` lines recovers 368717 and 11213 faces.
    - The STL exports hold 368717 triangles, above MuJoCo's 200000-face cap.
    - The .skp/.stl/.wrl zips are byte-identical between gc-ms and uv-vs-nr;
    the ones in uv-vs-nr look like GC-MS files copied in by mistake.
    - Neither instrument folder records units or prove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
2026-09-18 Add hash-addressed EAN-13 barcodes and a reader
    Every sample on the bench gets a printed EAN-13 label whose code is a pointer,
    not a container: sha256 of the sample's canonical payload, folded modulo 10^9,
    prefixed with the GS1 internal range 200 and given a check digit. Resolving a
    code means consulting barcodes/lookup_table.json, so a label stays valid as long
    as the record it points at keeps its identity.
    Nine digits is about 30 bits, so build_registry checks for collisions and
    re-hashes the loser with a recorded salt rather than trusting the odds.
    The catalogue is the full cross product of 20 flavour and fragrance raw
    materials (real CAS numbers) and five flask sizes -- 10, 20, 30, 50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
2026-09-18 Add powder compounds as a second phase, 200 barcodes total
    The catalogue now has two phases, each a full cross product of compounds and
    container sizes:
    liquid 20 compounds x 5 flasks (10/20/30/50/100 ml) SMP-0001..0100
    powder 20 compounds x 5 jars (30/60/125/250/500 ml) PWD-0001..0100
    Powders get jars, not flasks, because a solid needs a wide mouth for a spatula.
    The detector class name follows the phase -- flask_10ml..flask_100ml and
    jar_30ml..jar_500ml -- so there are ten vessel classes, and vessel_class is
    still derived from (phase, container_ml) rather than stored.
    Four compounds were in the wrong phase. Camphor (mp 175 C), Vanillin (81 C),
    Thymol (49 C) and Menthol (36 C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
2026-09-18 Put powders in the same flask series as liquids
    Powders move off the 30/60/125/250/500 ml jar series onto the same
    10/20/30/50/100 ml flasks the liquids use. Still 200 codes, 20 compounds per
    phase, each phase still a full cross product.
    The point is that container size no longer gives the phase away. With separate
    labware a detector could read "powder" off the vessel shape and skip decoding
    the barcode entirely -- the same shortcut the cross product exists to close, one
    level up. Sharing one series also collapses ten vessel classes to five:
    flask_10ml, flask_20ml, flask_30ml, flask_50ml, flask_100ml.
    This is a deliberate simplification, not a correction. A real powder belongs in
    a wide-mo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
2026-09-18 Add single-camera localisation: bounding box to a point on the bench
    A detector gives pixels; the robot needs metres. One camera is enough because
    a vessel standing on the bench has a known coordinate, so the pixel's ray can
    be intersected with the bench plane instead of triangulated.
    labvision/camera.py is the general geometry: intrinsics with Brown-Conrady
    distortion, pose from look-at / pan-tilt / MuJoCo / solvePnP, ray-plane
    intersection, the analytic Jacobian that turns pixel error into millimetres,
    the horizon line, and the plane homography with a hand-written DLT fit -- the
    calibration-free route when every answer lies on one plane.
    labvision/scene.py is this room (14x5x3, camera at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
2026-09-18 Size the detector for the GoPro scene camera: native input, 1080p numbers
    The scene's camera is now a GoPro in Linear mode at 1080p, 3.23 m from the
    bench. At that range the bottle kit spans 19 px of side (100 ml) to 48 px
    (2 L) in the frame, so only the 2 L bottle clears the reliable floor and any
    downscaling before inference loses the whole kit. The detector therefore
    defaults to the frame's own input size instead of 960, and the README and
    the module docstring carry the per-bottle table for 1080p and 4K, with 4K or
    the Narrow lens as the fixes. The test pins the 1 L bottle at 25 x 62 px.
    Claude-Session: https://claude.ai/code/sessi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
2026-09-18 Turn bottle labels to ladder orientation, and make the reader find them
    A barcode wrapped upright round a cylinder has its bar widths squeezed unevenly
    and stops decoding just under 60 degrees of arc, which capped the 100 ml label
    at 51 % magnification. Turned a quarter turn, only the bar lengths are squeezed:
    all 100 powder labels decode at 60, 90 and 120 degrees, down to 3 px/module.
    Labels are now sized by the wall, up to 200 %: 96 % on the 100 ml bottle.
    The reader could not find such labels: its localiser closed the image with a
    flat kernel only, which never bridges bars that lie flat, and 35 of 100 turned
    labels failed. Each closing kernel is now tried both ways round. About 60 ms
    per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
2026-09-18 Commit the 100 labelled powder bottles
    One GLB per powder sample in assets/agrochemical-bottles/labelled, each carrying
    the version-4 barcode of its own sample on the bottle of its own size, so the
    simulation side can use them without installing labvision. About 60 MB.
    They are deterministic build output, and a new test fails when they drift from
    what the current catalogue, label layout or kit would produce.
2026-09-18 Turn the minihannover scene into the perfumery lab
    Rebuild models/minihannover_scene.xml after the reference lab video: a
    14 x 5 x 3 m white cleanroom around the bench, generated by the new
    scripts/generate_lab_room.py (walls, glass partitions, ceiling with LEDs,
    shelving gantry with ~690 amber bottles, wall bench, entrance corner,
    wash zone, drying rack, snorkels, office behind the glass).
    The scene composes the converted assets: one sink (recoloured white),
    five analytical balances, the GC-MS and UV-Vis-NIR on a left-wall bench,
    HDPE jars and bottles in the entrance corner, and seven loose amber
    bottles as the only movable bodies.
    New converters and assets:
    - tools/convert_glb.py (GLB ->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
    [amber_060ml_00.obj, amber_060ml_01.obj, amber_100ml_00.obj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]
2026-09-18 Stick the liquid barcodes onto the amber bottles
    labvision.bottles now has a kit per phase: powders go on the white HDPE bottles
    as before, liquids on the amber glass ones in assets/amber-bottles. The kit is
    picked from the sample's phase and the bottle from its container_ml, so 100 ml,
    which both series have, resolves to the right bottle. The liquid sizes already
    matched the kit, so no liquid barcode changed; its 60 ml bottle is unused.
    Labels go on in ladder orientation and fill the straight wall, which is what
    binds on every amber bottle: 63 % magnification on the 10 ml, 174 % on the
    100 ml. The amber files hold a closed bottle with the cap listed first, so the
    bottle is now taken to be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
2026-09-18 Put the barcoded sample bottles into the minihannover scene
    Every sample container in models/minihannover_scene.xml is now a catalogued
    sample carrying its EAN-13 label: six powders in white HDPE bottles in the
    entrance corner (replacing the unlabelled bottles and the HDPE jars) and seven
    loose amber bottles of liquid on the bench, all five sizes of each, turned so
    the labels face the room.
    tools/build_labelled_bottles.py builds assets/labelled_bottles from the labelled
    GLBs: convert_glb.py drops textures, and here the label is the point. Meshes are
    shared per bottle size; a sample adds its label PNG and a small MJCF. The label
    is a separate visual-only geom, no mass and no contacts.
    Angle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
    [bottle_1000ml_body.obj, bottle_1000ml_cap.obj, bottle_1000ml_label.obj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]
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2026-09-19 Stock the gantry shelves with the barcoded sample library
    The ~690 decorative amber bottles on the shelving gantry, an invented shape with
    blank labels, are replaced by the barcode catalogue: every sample the scene does
    not place by hand stands on the gantry once. 94 powders in white HDPE bottles on
    the two lower shelves, 93 liquids in amber flasks on the third, a compound's
    sizes side by side, labels facing the aisle. With the 13 the scene places, all
    200 catalogue samples are in the room, each exactly once.
    A kit bottle is 14 000 to 50 000 triangles, so build_labelled_bottles.py now also
    writes light stand-ins (the same silhouette revolved in 24 segments, about 1 500
    triangles), half-reso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
    [bottle_1000ml_shelf_body.obj, bottle_1000ml_shelf_cap.obj, bottle_100ml_shelf_body.obj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]
2026-09-19 Scatter the sample bottles: nothing in the room is sorted
    The point of the scene is to show that every sample can be found wherever it
    stands, so position must say nothing about identity. The gantry library is now
    dealt at random: powder bottles and liquid flasks of every size mixed over all
    four shelves and both faces, uneven gaps, varying depth, labels turned up to 25
    degrees off the aisle. Bottles still never overlap along a shelf.
    The thirteen hand-placed samples are mixed too: three powder bottles are loose on
    the worktop among the amber flasks, and three flasks stand in the entrance corner
    among the powder bottles. The loose bodies are now loose_1..7, since they are no
    longer all ambe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
2026-09-19 Draw only as many bottles of a size as the scene holds, and score small bottles fairly
    random_layout could ask for a fifth bottle of one size when the scene has four
    bodies of each; main skipped it in silence, so `--bottles min,max` undershot
    without saying so. The layout now caps every size at what the scene can
    place, so every bottle drawn is one that stands.
    The scorer dropped bottles under `--min-pixels` from the truth but still
    counted a box on one of them as a false positive, so a correct detection of a
    far bottle raised "false boxes per frame". A box that overlaps a bottle too
    small to be required is now neither a hit nor a miss.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
2026-09-19 Benchmark the detectors on the whole perfumery lab from the scene's own cameras
    render_perfumery.py renders minihannover_scene.xml as it is, from its
    walkthrough cameras and from the vision system's two GoPros, with random
    bench layouts, and writes the truth for every catalogue bottle with a pixel in
    view: the loose ones, the entrance corner and the 187 on the gantry, each
    with its visible box, its whole silhouette, how much of it shows and whether
    it stands on the bench, a shelf or elsewhere. The simulator's state writes
    that truth and nothing else; the detector only ever sees the RGB frame.
    perfumery_eval.py scores a backend per set, by bottle and by apparent size,
    and names what every fal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
2026-09-19 Add the research vault and the experiment plan it argues for
    The vault is 233 sources across four axes -- Lie groups, geometric
    optimization, vision for robot arms, and a fourth document that measures
    the other three for gaps and fills seven of them. 329 markdown notes,
    one per source, each carrying its claims with evidence tags and page
    numbers. The 189 arXiv PDFs stay ignored: they are 1.3 GB and every one
    of them is a download away.
    experiments.md is what the vault says to do next. It reads the shortlist
    of policy families against two things the vault already knows. LabUtopia
    ran ACT against Diffusion Policy on Isaac Sim lab tasks and ACT won on
    every level-2 task and held its success ou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
    [q5-calibration-servoing.json]
2026-09-19 Add the dashboard: a one-screen mission-control console for the demo
    dashboard/ shows a judge what the autonomous system is doing, stage by
    stage: perceive, identify, plan, move, dose, verify. React 19, TypeScript,
    Vite and Tailwind; the mass chart is plain SVG.
    It opens on a deterministic replay of one recipe in the simulation's own
    workcell: the minihannover bench, its five balances, the general and wrist
    cameras and the seven loose containers with their real sample ids. The
    same screen switches to the live system over WebSocket or SSE, fed by the
    small Python bridge in dashboard/bridge (a mock run and a MuJoCo adapter).
    The package carries its own .npmrc pointing at the public npm regis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
2026-09-19 Remove the robot viewer prototype, superseded by dashboard/
    Martí's dashboard/ (mission-control console + labbridge) covers the same
    ground — live general/wrist camera streams and robot state — and much
    more, so this simpler standalone viewer is no longer needed.
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2026-09-19 overnight: name the sample in a detector box by its ArUco ring
    labvision.identify reads the DICT_4X4_250 ring (same detector parameters as
    wrist_scan.py) inside each detector box and its margin, lets the markers whose
    centre lies inside the box vote, and resolves the winner through the lookup
    table's marker_id. A tie names nobody. identify_frame reads the whole frame
    without a detector, one identity per id. A crop that reads nothing is read
    again enlarged, never skipping its own size: on blurred synthetic markers,
    starting enlarged lost reads (11/20 against 19/20 at 18 px).
    Claude-Session: https://claude.ai/code/session_01YU7vSDS6wYe6SAD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
2026-09-19 overnight: hand the dashboard what the cameras saw, in its own vessel shape
    labvision.world.PerceivedBottle is one bottle the vision system found: its
    bench position, the fixed camera's score, and the sample, marker and phase the
    wrist camera read, with whether the position was refined from the ring.
    to_dashboard turns a list of them into the console's PerceivedVessel records
    (dashboard/src/state/types.ts), class named by kit once the sample is known,
    so the bridge can publish perception instead of its mock. A test feeds them to
    the bridge's own perception_state when the bridge is importable.
    Claude-Session: https://claude.ai/code/sessio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
2026-09-19 overnight: fixed camera proposes, wrist camera confirms, as pure functions
    labvision.perception holds the vision system's core, frames and calibrated
    cameras in, bottles out, so a render loop, the console bridge or real GoPros
    can run it alike. propose places the fixed camera's boxes on the bench (base
    anchor, plane z = 0.90 in the scene frame, 25 mm radius until the bottle is
    known), filters and merges them. confirm reads every ring in the wrist frame,
    takes the nearest to the proposal's projection, and refine places the bottle
    from its ring's radius and height, read from the label mesh. A ring whose
    bottle would stand more than 5 cm from the proposal is a neighbour seen past
    it and is pass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
2026-09-19 overnight: benchmark naming bottles from the wrist camera, whole frame vs boxes
    scripts/wrist_identify_bench.py asks, for every bench bottle half visible in a
    wrist frame, whether its marker was read on it: in the whole frame, inside a
    detector's boxes (World with bottle or current prompts, COCO), or inside the
    true boxes with and without enlarging the crop. It counts wrong ids and ids no
    bottle in view carries, and splits by distance and bottle. render_perfumery.py
    gains --wrist-range so the wrist set can go past 0.6 m.
    Claude-Session: https://claude.ai/code/session_01YU7vSDS6wYe6SADceJXzki
2026-09-19 overnight: name the bottle whose ring places it on the proposal, not the nearest ring
    From an independent review of tonight's code:
    - confirm ranked rings by pixel distance, so a 50 ml flask 4.5 cm behind a
    10 ml one, inside the 5 cm limit, won because its ring sat nearer the aim
    point. Every ring near the proposal is now placed as the bottle it names and
    the one standing closest to the proposal wins; rings with no table row are
    skipped.
    - refine took the centre of all of a ring's markers, which the markers at
    +-45 degrees pull away from the facing point: 6.8 mm off on a 1 L bottle in
    the new test against 1.5 mm from the most frontal marker, which it now uses.
    - identify_frame me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
2026-09-19 Refine arm eye-in-hand: 6 positions for Franka/Kinova + 25° tilt variant
    Franka Panda and Kinova Gen3 now cover 6 bench positions each; add a 25°
    tilted eye-in-hand variant that renders bottle sides + barcodes far more
    legibly than the pure top-down. UR10e stays at 3 positions: swept its
    wrist joints and confirmed its bulky forearm crosses any tight eye-in-hand
    frame, so it's kept only as an "arm in action" shot.
    arm_pose_render.py gains POSE_OVERRIDE / TILT / SKIP_GENERAL / OUT env
    knobs and a comma-separated ONLY_ARM list.
    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
2026-09-19 Add synthetic barcode-detection dataset v1 (generator + sample)
    300 Isaac RTX frames of the open lab across 5 cameras, auto-labelled by
    EAN-13 barcode id: 80,040 COCO boxes over 180 categories + semantic masks,
    with per-frame light domain randomization. Each bottle mesh is tagged with
    its barcode id as a Semantics class, so a per-class tight box is a per-bottle
    box labelled by product.
    The full 356 MB dataset (images + masks + COCO instances.json) is on Google
    Drive (General MAFER AI/hackathon/lab_dataset_v1); the repo keeps the
    reproduction scripts (dataset_gen.py, build_coco.py) and a visual sample.
    Claude-Session: https://claude.ai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
2026-09-19 Hollow the flasks for collision, and stand the beaker on an open balance
    Two things the pipetting MVP faked, now real.
    The flasks were convex. MuJoCo collides a mesh as its convex hull, so the
    glass was a solid slug and the only way to get a tip inside was to exclude the
    contact --- which meant a badly aimed tip passed through the glass instead of
    striking it. Each vessel now carries three rings of twelve overlapping boxes,
    body, shoulder and neck, plus a base disc. Measured in the scene: a tip 12 mm
    off the axis makes six contacts with the glass, 8 mm and less goes down the
    bore. The exclusions are gone. It costs about 37 collision geoms per vessel
    and the scene runs at 12.8x realtime, fas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
    [part_00.obj, part_01.obj, part_02.obj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]
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2026-09-19 Add the Pasteur pipette asset: a 3 ml graduated transfer pipette
    Generated headless in Blender (generate_pasteur_pipette.py). MJCF, URDF, GLB
    and the .blend, split collision meshes for bulb and stem, an Isaac Lab loader
    and a preview.
    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
    [pasteur_pipette.blend]
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2026-09-19 Give the cap a thread that actually engages the neck
    The kit's neck has had a real helix since it was written; the cap was a smooth
    bore with clearance over it, so it slipped on and could never grip. Adds the
    mating internal helix, a --pair mode that writes the pair and checks it, and
    two clearances as sweepable constants: THREAD_CLEARANCE (radial, the one that
    decides whether a recap cross-threads) and SEAT_CLEARANCE (axial over the lip,
    without which the cap's ceiling and the lip are coincident faces).
    All four neck sizes screw through 720 degrees in 72 steps with no BVH overlap.
    PP20 travels 4.40 mm, which sets the iris clamp's regrip budget. The catalogue
    is untouched: make_cap defaults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
    [thread_pair_PP18.blend, thread_pair_PP20.blend, thread_pair_PP25.blend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]
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2026-09-19 Use the amber bottle and its PP25 cap in the uncap-and-pipette hand
    The MuJoCo scene, the URDFs, the .blend and the viewer now take the 60 ml
    amber bottle of assets/amber-bottles with its PP25 cap instead of the iris
    clamp kit's placeholder bottle. Its Ø28 mm ribbed cap is the one the clamp
    was built for; the blades close on its Ø28.8 mm tamper band (74.8 deg).
    Masses come from the meshes (57.8 g, 2.5 g), the thread is PP25 (2.75 mm
    pitch, 5.5 mm rise, hinge follows 3.5 deg), and the bottle still collides
    as a hollow ring of boxes so the pipette goes down the neck. All MuJoCo
    checks pass.
    FULL_PHYSICS_ISAAC.md is rewritten from the current MuJoCo state: the
    baseline to match, collision fi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
    [amber_cap.stl, amber_glass.stl, iris_bottle.stl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]
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2026-09-20 Rebuild the vertical hand assets for the narrow cage page
    gripper-design/vertical_hand.html is now the 154 mm U-channel cage: the iris
    clamp slides back along X on the +Y plate (parked at x = -90 under the
    pipette), the micropipette hangs fixed on the bottle's axis and only goes
    down, the jaws reach their carriages through tabs in their own comb bands,
    21 steps. vertical_hand_rig.py mirrors the page's new parameter block, state
    and joint tree (19 joints, 8 actuated, no swing); the generator builds the
    windowed side plates, the back plate, the servo head, the X rail and the
    fixed pipette, and its checks and the MuJoCo playback are retargeted to the
    new step numbers. All four outputs still agr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
    [clamp_lift__black.stl, clamp_lift__gray.stl, clamp_slide__black.stl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]
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2026-09-20 Vertical hand: no arm stub, collision on every part, approach and retreat
    The model now ends at the servo head's top plate; the UR flange and arm stub
    are gone. Every mesh builder carries a collision spec, so the MJCF and the
    URDF get a physical body for each part: boxes for the softened boxes and the
    cradles (chord boxes along the parabola, liner plus plate), cylinders for the
    turned parts, rings as circles of boxes with open bores, the side plates as
    two slabs plus a convex hull for the toe. 322 primitives; hand parts collide
    with the bottle, the cap and the floor, never with each other. The URDF's
    collision geoms are checked against the MJCF's in MuJoCo.
    A new `approach` joint (property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
    [col_hand_14.stl, col_hand_17.stl, hand__linkgray.stl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]
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2026-09-20 Hang the black cage hand on the rail arm as the gripper
    The narrow vertical hand of gripper-design/vertical_hand.html, built as plain
    solids and fitted to the UR10e in place of the Robotiq 2F-85.
    The page itself is redesigned to the width Eki asked for: the cage is as wide
    as the iris housing plus a slight margin, 154 mm overall (Ø138 + 4 mm of
    clearance and a 4 mm plate a side). The iris now slides straight back along
    the +Y plate instead of sideways, the pipette hangs fixed on the vial's axis
    and only descends, and the jaws reach their carriages through tabs in their
    own comb bands, so the gripper is never wider than its cradles. The cost is
    100 mm of height: the flange sits at 530 mm. A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
    [vertical_hand_minimal.blend]
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
